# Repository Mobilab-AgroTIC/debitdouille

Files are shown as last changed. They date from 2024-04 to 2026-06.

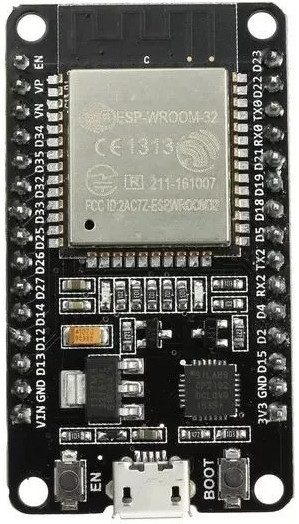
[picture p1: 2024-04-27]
Branchements/esp32.jpg

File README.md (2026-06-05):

# Débitdouille

Débitdouille est un système à construire soi-même permettant de suivre les paramètres de pulvérisation en temps réel.

Ces paramètres sont :
- La pression du circuit,
- les débits des sections,
- la vitesse d'avancement.

Tous ces paramètres sont affichés dans la cabine sur le smartphone (Android) du tractoriste via Bluetooth.
Débitdouille a été développé par la CA34 et le mobilab AgroTIC dans le cadre du projet Occitanum. Il est maintenant largement amélioré par Furgo (furgo.fr)

Le [tutoriel d'installation est disponible sur ce lien ](https://mobilab.agrotic.org/2024/11/28/debitdouille/)

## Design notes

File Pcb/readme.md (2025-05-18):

# Débitdouille – Électronique

> Gestion de la partie électronique du projet Débitdouille.

---

## 📑 Description

La partie électronique de **Débitdouille** est responsable de :
- L'acquisition de mesures physiques (débit, pression).
- La gestion de l'alimentation.
- La communication avec l'application.

---

## 🖧 Architecture Électronique

```text
+-------------------------------+
|           Capteurs            |
| - 2 x Débitmètres SIKA         |
| - 1 x Capteur de pression      |
+--------------+----------------+
               |
      +--------v--------+
      |  Microcontrôleur  |
      |     ESP32         |
      +--------+--------+
               |
      +--------v--------+
      |   Module de comm  |
      |    (Wi-Fi / BLE)  |
      +------------------+
```
## 📋 Historique des Versions

### [v1.1] - A venir
- Protection contre l'inversion de polarité 12V
- Ajout résistane pullup 
- Ajout ports débitmètres supplémentaires
- Routage : cloutage, largeur de piste 

### [v1.0] - 2025-05-12
- Première version en production.
- Schéma validé.
- Déploiement du PCB v1.
- Tests fonctionnels réalisés.

## 👥 Auteur et contributeurs 

Christophe Auvergne CA34

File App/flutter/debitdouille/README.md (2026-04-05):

# debitdouille_v2

A new Flutter project.

## Getting Started

This project is a starting point for a Flutter application.

A few resources to get you started if this is your first Flutter project:

- [Lab: Write your first Flutter app](https://docs.flutter.dev/get-started/codelab)
- [Cookbook: Useful Flutter samples](https://docs.flutter.dev/cookbook)

For help getting started with Flutter development, view the
[online documentation](https://docs.flutter.dev/), which offers tutorials,
samples, guidance on mobile development, and a full API reference.

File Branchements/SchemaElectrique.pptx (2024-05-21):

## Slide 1

12V

GND

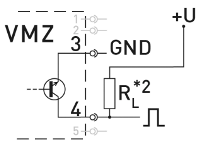
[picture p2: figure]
Push-Pull: VMZ GND 5-1-0— NPN Open Collector: 140— VMZ 31 GND 5 _I_OD PNP Open Collector: VMZ GND *1: Push-Pull switching outputs of several VMZ.2 may not be connected in parallel. *2: Recommendation Pull-Up / Pull-Down resistance RL -2.5 kQ (12 V) or -5 kQ (24 V). Ensure that the maximum si nal c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
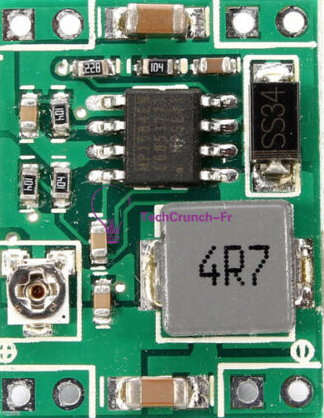
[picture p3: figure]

5V

GND

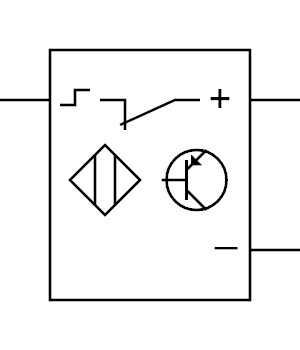
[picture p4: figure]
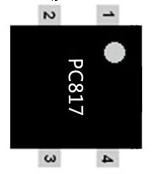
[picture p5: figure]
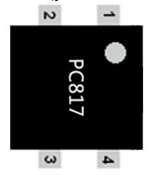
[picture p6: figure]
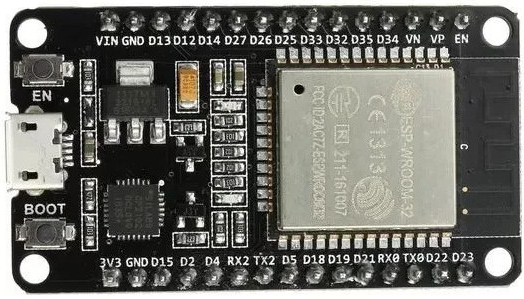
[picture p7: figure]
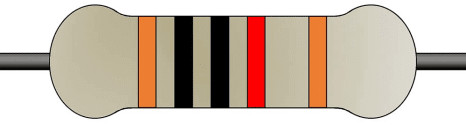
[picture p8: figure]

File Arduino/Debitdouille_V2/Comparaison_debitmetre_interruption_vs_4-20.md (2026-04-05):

# resultats mesure débit avec interruptions 

## Extrait de données brutes PCNT1 vs 4-20_1

## Données PCNT1–4 vs 4-20_1–4

| P (bar) | PCNT1 | PCNT2 | PCNT3 | PCNT4 | 4-20_1 | 4-20_2 | 4-20_3 | 4-20_4 | Vitesse (km/h) |
|:---:|:---:|:---:|:---:|:---:|:---:|:---:|:---:|:---:|:---:|
| -0.30 | 3.96 | 0.00 | 0.00 | 0.00 | 3.99 | 0.00 | 0.00 | 0.00 | 0.4 |
| -0.30 | 4.08 | 0.00 | 0.00 | 0.00 | 3.98 | 0.00 | 0.00 | 0.00 | 0.4 |
| -0.30 | 3.96 | 0.00 | 0.00 | 0.00 | 3.99 | 0.00 | 0.00 | 0.00 | 0.4 |
| -0.30 | 4.02 | 0.00 | 0.00 | 0.00 | 3.98 | 0.00 | 0.00 | 0.00 | 0.4 |
| -0.30 | 4.02 | 0.00 | 0.00 | 0.00 | 3.99 | 0.00 | 0.00 | 0.00 | 0.3 |
| -0.30 | 4.02 | 0.00 | 0.00 | 0.00 | 3.97 | 0.00 | 0.00 | 0.00 | 0.3 |
| -0.30 | 3.96 | 0.00 | 0.00 | 0.00 | 3.96 | 0.00 | 0.00 | 0.00 | 0.2 |
| -0.30 | 4.02 | 0.00 | 0.00 | 0.00 | 3.97 | 0.00 | 0.00 | 0.00 | 0.2 |
| -0.30 | 3.96 | 0.00 | 0.00 | 0.00 | 3.98 | 0.00 | 0.00 | 0.00 | 0.6 |
| -0.30 | 3.96 | 0.00 | 0.00 | 0.00 | 3.92 | 0.00 | 0.00 | 0.00 | 0.6 |
| -0.30 | 3.96 | 0.00 | 0.00 | 0.00 | 3.97 | 0.00 | 0.00 | 0.00 | 0.1 |
| -0.28 | 3.96 | 0.00 | 0.00 | 0.00 | 3.95 | 0.00 | 0.00 | 0.00 | 0.1 |
| -0.28 | 4.02 | 0.00 | 0.00 | 0.00 | 3.97 | 0.00 | 0.00 | 0.00 | 0.6 |
| -0.28 | 3.96 | 0.00 | 0.00 | 0.00 | 3.96 | 0.00 | 0.00 | 0.00 | 0.6 |
| -0.28 | 4.02 | 0.00 | 0.00 | 0.00 | 3.95 | 0.00 | 0.00 | 0.00 | 0.1 |
| -0.28 | 4.02 | 0.00 | 0.00 | 0.00 | 3.97 | 0.00 | 0.00 | 0.00 | 0.1 |
| -0.28 | 3.96 | 0.00 | 0.00 | 0.00 | 3.99 | 0.00 | 0.00 | 0.00 | 0.5 |
| -0.28 | 4.02 | 0.00 | 0.00 | 0.00 | 3.99 | 0.00 | 0.00 | 0.00 | 0.5 |
| -0.28 | 4.02 | 0.00 | 0.00 | 0.00 | 3.94 | 0.00 | 0.00 | 0.00 | 0.2 |
| -0.28 | 3.96 | 0.00 | 0.00 | 0.00 | 3.92 | 0.00 | 0.00 | 0.00 | 0.2 |

## Analyse 
### 📊 Données analysées

- **Nombre de points** : ~70 mesures  
- **Plage de pression (P)** : -0.30 à -0.27 bar  
- **Variables comparées :**
  - **PCNT1 (L/min)** → mesure avec interruptions (non PCNT) avec un ESP32-C3
  - **4-20_1 (L/min)** → signal issu de la conversion 4–20 mA

---

### 📈 Résultats statistiques

| Mesure | Moyenne (L/min) | Écart-type (L/min) | Observations |
|:---|:---:|:---:|:---|
| **PCNT1** | **3.97** | **0.06** | Légère dispersion (valeur brute capteur) |
| **4-20_1** | **3.92** | **0.02** | Signal plus lissé, filtrage probable |
| **Différence (PCNT1 − 4-20_1)** | **+0.05** | **≈ 0.05** | Décalage moyen de +0.05 L/min |

- **Corrélation linéaire (r)** ≈ **0.95 – 0.98** → excellente cohérence entre les deux signaux.  
- **Biais systématique** : le signal 4–20 mA **sous-estime d’environ 1,3 %** le débit Interrupt.

---

L’analyse des écarts observés entre **PCNT1** et **4-20_1** montrait une dispersion anormale pour PCNT de ±0.06 L/min.  
Après vérification, cette erreur ne provient **pas d’un décalage de calibration**, mais du **temps d'intégration des pulses (1000 ms)** utilisé pour mesurer la fréquence du débitmètre.

---

### ⚙️ Analyse du problème

- Fréquence moyenne du capteur : **≈ 65 Hz** (soit ~65 impulsions/s)
- À **200 ms**, cela correspond à environ **13 impulsions** par période.

| Pulses comptés | Débit calculé (L/min) |
|:---:|:---:|
| 12 | 3.6 |
| 13 | 3.9 |
| 14 | 4.2 |

➡️ Une variation de ±1 pulse entraîne une **erreur de ±0.3 L/min**, soit près de **8 % d’écart** !

- À **1000 ms**, cela correspond à environ **65 impulsions** par période.

| Pulses comptés | Débit calculé (L/min) |
|:---:|:---:|
| 64 | 3.92 |
| 65 | 3.96 |
| 66 | 4.02 |

➡️ Une variation de ±1 pulse entraîne une **erreur de ±0.06 L/min**, soit près de **1.3 % d’écart**

---

### ✅ Solution appliquée

Allonger la période de mesure permet de diminuer l'écart lié au comptage ou non d'un pulse :

### ⚙️ Proposition de correction (calibration de l'un ou l'autre)

Deux approches possibles selon le type de régulation souhaité :

#### 1. Correction par offset constant du capteur 4-20
\[
Q_{\text{corrigé}} = Q_{4-20_1} + 0.05
\]

#### 2. Correction par facteur de gain du capteur 4-20
\[
Q_{\text{corrigé}} = Q_{4-20_1} \times 1.013
\]

> ✅ Ces formules ramènent la moyenne du capteur 4–20 mA au même niveau que celle du capteur PCNT1.

---

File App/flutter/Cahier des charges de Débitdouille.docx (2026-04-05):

Cahier des charges de Débitdouille

Debitdouille est un système open source permettant de suivre en temps réel les paramètres de pulvérisation pour un agriculteur, dans son tracteur, sur son téléphone.

Boitier “hardware”

Un boitier est installé sur le pulvé, il est composé :

- d’un ESP32, qui envoie les données en Bluetooth.

- De paires de débitmètres, un gauche et un droit. Il y a par défaut 1 paire, mais on peut aller jusqu’à 4 paires.

- D’un capteur de pression

- d’un GNSS permettant de calculer la vitesse.

Ce boîtier est branché depuis la cabine du tracteur, en 12V, sur une prise 3 plots. Il possède un régulateur 5V pour faire fonctionner les capteurs.

Les débitmètres et le capteur de pression sont à étalonner, au moins à l’installation du système, et au mieux une fois par an.

Les données du boitier installé sur le puvlé sont affichées sur le smartphone de l’agriculteur via connexion bluetooth. Il y a donc 3 types d’infos principales à afficher ;

· Pression de la cuve, grâce à un capteur de pression

· Débit. Il peut y avoir plusieurs débitmètres installés sur le pulvé. Ils viennent par paire : Débit gauche 1 et débit droit 1, Débit gauche 2 et débit droit 2, Débit gauche 3 et débit droit 3.

· La vitesse est également donnée avec un GPS car celle donnée par le tracteur n’est pas bonne.

L’application peut choisir de se connecter à un objet en bluetooth BLE pour recevoir les trames DATA toutes les secondes en format JSON dans le format suivant :

{"P":"1.24","V":"7.30","DG1":"2.34","DD1":"0.29","DG2":"0.87","DD2":"0.00","DG3":"2.04","DD3":"1.11"","DG4":"2.04","DD4":"1.11"}

Application “software”

L’application doit être simple, intuitive, sans fioritures.

## Technologie :

L’application est développée en Flutter. Elle est composée de plusieurs fichiers qui correspondent à une architecture classique d’un projet flutter (main, screens, widgets, etc)

## Pages :

Je décris ici les pages. Le style est simple : tout est en fond noir, écrit en blanc, le plus gros possible.

- Base :

Ceci est commun à toutes les pages. C’est TOUJOURS affiché, sur les pages décrites ci-dessous !
Il y a un en-tête avec un bouton « paramètres ». Ceci ouvre un onglet sur le côté, et on peut alors choisir entre les pages :

La page Accueil, la page de connexion, la page d’Etalonnage des capteurs, et la page de paramètres.

Sur l’en-tête, on trouve également un petit rond vert. Ce rond vire au rouge si aucune donnée n’a été reçue depuis 3secondes. Cela permet de s’assurer que le système est toujours connecté.

il y a un bouton en bas à droite permettant de simuler l’arrivée d’une trame json. Ce bouton peut être masqué, cela dépendra des options choisies dans la page des paramètres de l’appli.

A gauche de ce bouton, tout en bas, on peut lire la dernière trame arrivée. Cela permet de débugguer. Cette trame json provient du bouton simulation OU du module Bluetooth.

L’exemple est donné ci-dessous :

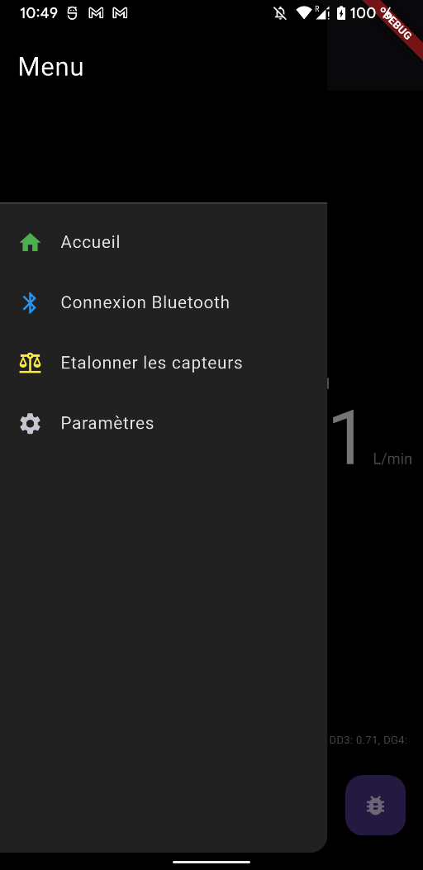
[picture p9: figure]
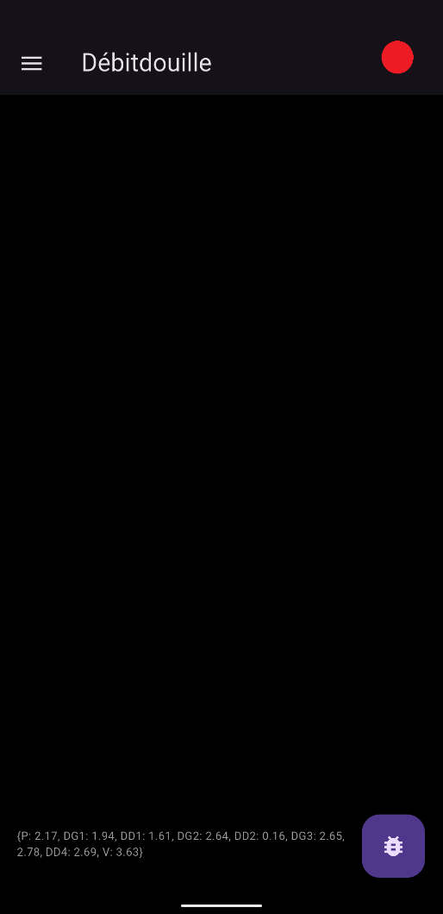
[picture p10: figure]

A gauche, le scaffold avec les objets principaux. A droite, le menu avec les 4 pages.

- page Accueil

La page d’accueil de débitdouille est noir, avec écrit en blanc et en gros plusieurs chiffres :

- En haut, centré, la pression.

- Au milieu, les débits :

- le (ou les) débits gauches à gauche

- le (ou les) débits droits à droite

- En bas, centré, la vitesse.

Comme c’est la page d’accueil, au début, toutes les valeurs sont à zéro.

Il est possible d’avoir plusieurs paires de débits gauche ou droit. Cela dépendra des options choisies dans la page des paramètres de l’appli.

Quoi qu’il arrive, l’affichage des débits est toujours au milieu de l’app, sur la gauche pour le debits gauche, et sur la droite pour les débit droits. Cela peut aller jusqu’à 4 débits gauche et 4 débits droit. La trame json contiendra toujours 4 paires de débits

Ces chiffres sont en gros. Au dessus de chaque chiffre, il est écrit en plus petit ce que c’est (pression, DG1, DG2, DD1, DD2, vitesse, ). Il y a 2 décimales pour ces valeurs. Il y a aussi l’unité (bars, L/min ou km/h) affiché en petit, à droite du chiffre.

Un exemple de cette page :

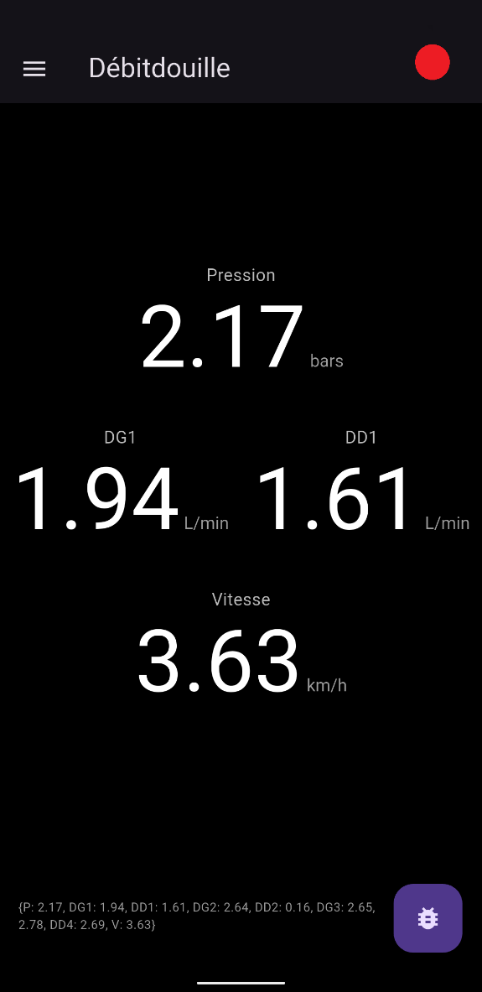
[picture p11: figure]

Ci-dessus, la page d’accueil.

- page Connexion

La page de connexion permet d’appairer le boîtier. On peut lancer un scan et voir les appareils BT à proximité. Dès qu’une connexion est faite avec un module, on revient automatiquement sur la page principale, et on voit que les données sont mises à jour via le module Bluetooth. Si ça bugue, par exemple mauvais UUID, ça met un message d’erreur « connexion échouée »

- page Paramètres

La page des paramètres présente des boutons, qui permet de modifier l’interface :

- On peut choisir le nombre de paires de débits avec 1, 2, 3 ou 4 paires. Cela forcera à l’écran le nombre de paires de débits à afficher.
- Un bouton à cocher ‘debug’ permet de masquer ou afficher la trame json, affichée dans la page principale, faisant office de débug.
- Un bouton à cocher ‘simulation’ permet d’afficher sur la page principale un petit bouton, qui envoie une trame json fictive a chaque appui du bouton. Le bouton est masqué par défaut.

Si on rallume l’application, elle garde en mémoire les infos (il ne faut pas remodifier les réglages a chaque fois). Il n’y a pas de boutons « enregistrer » dans cette page, ça se fait automatiquement.

- page Calibration

Chaque capteur est calibré avec un coefficient A et B, de la façon ValeurCalibrée = A * ValeurBrute + B. Les trames JSON n’envoie que les valeurs calibrées.

La page de calibration permet de visualiser les coefficients du capteur, stocké sur l’ESP32, et de les corriger.

Chaque capteur est accessible avec une liste d’onglets en haut de l’écran, comme un carroussel de tous les capteurs (Pression, DG1, DG2, …)

Dans la suite, je parle de l’onglet P (pression) mais les autres sont similaires.

On a un bouton « récupérer les coefficients », qui permet d’afficher dans les CASES a ET b les coefficients stockées dans l’ESP32. La trame envoyée est de ce style, il suffira juste de filtrer pour le capteur voulu

{

"coeff": {

"DG1": {"A": 1.0, "B": 0.0},

"DD1": {"A": 1.0, "B": 0.0},

"P": {"A": 1.0, "B": 0.0}

}

On affiche alors : La Valeur brute (l’inverse de la formule mathématique ci-dessus), et la valeur calibrée.

On peut modifier manuellement les cases A et B pour changer de coefficient, cela modifiera la valeur calibrée affichée directement. Si on appuie sur « envoyer les coefficients », on va envoyer une trame json à l’esp32, qui va écraser les anciens coefficients et les mettre à jour. Cette trame json est du style :

{

"update_coeff": {

"DG1": {"A": 1.2, "B": -0.1},

}

}

Un exemple de page :

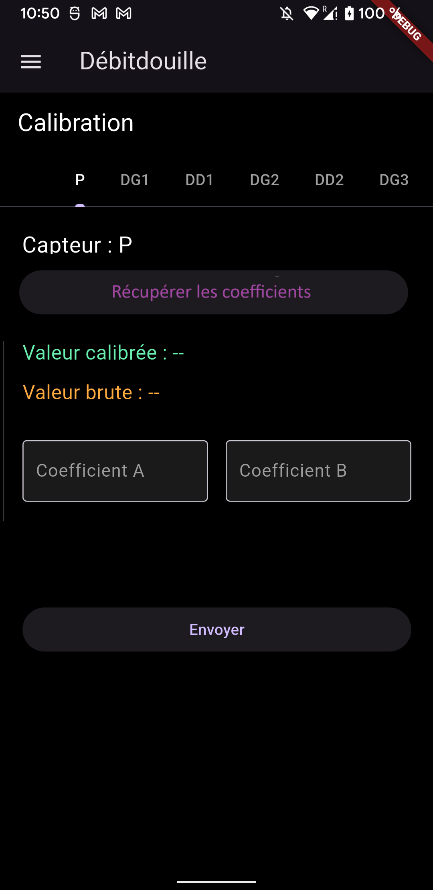
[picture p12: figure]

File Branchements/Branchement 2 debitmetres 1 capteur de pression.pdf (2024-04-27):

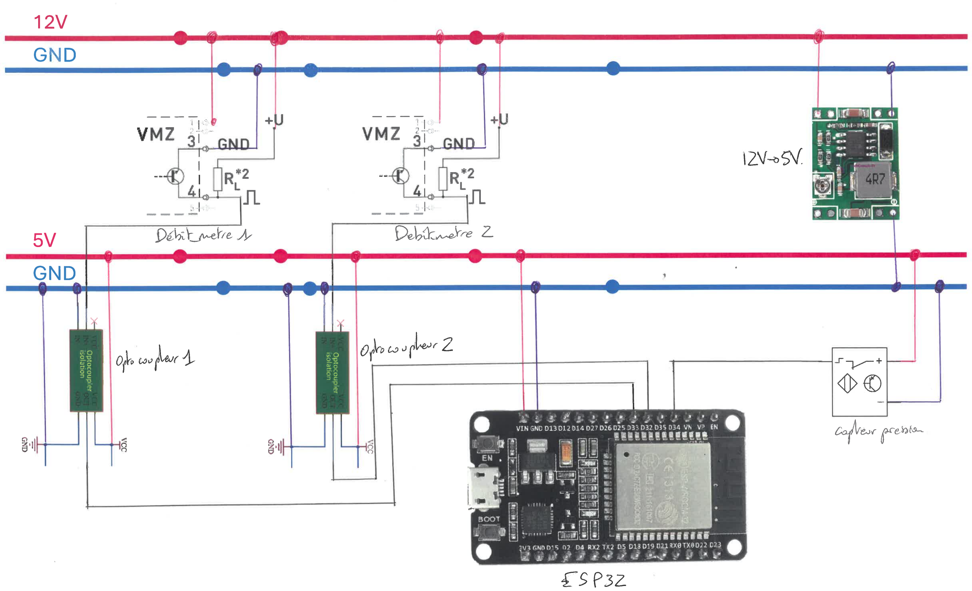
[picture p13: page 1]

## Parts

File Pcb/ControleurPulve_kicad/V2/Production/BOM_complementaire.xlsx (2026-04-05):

Qté | Part | MF | MPN | Comment | Lien 1 | Lien 2
1 | PCB carte mère | JLC PCB
1 | regulateur DC DC |  | TRS2-2450 | 5V 2A
1 | XIAO ESP32-C3
1 | antenne Bluetooth ipex
1 | GPS neo 7M |  | GY-NEO6MV2
1 | connecteur ipex SMA
8 | cavalier
1 | DC jack receptacle |  |  | optionnel si utilisé
1 | connecteur extension | JST | ? | optionnel si utilisé
1 | connecteur I2C |  | ? | optionnel si utilisé

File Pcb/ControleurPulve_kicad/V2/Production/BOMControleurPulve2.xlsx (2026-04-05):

Designator | Comment | Datasheet | Footprint | Qty | DNP | JLCPCB Part | MPN
C1,C4,C5,C7,C10,C11,C13,C15,C17,C18 | 100nF | ~ | Capacitor_SMD:C_0603_1608Metric,Capacitor_SMD:C_0603_1608Metric_Pad1.08x0.95mm_HandSolder,Capacitor_SMD:C_0805_2012Metric | 10 |  | C1591 | CL10B104KB8NNNC
C2 | 470uF 50V | ~ | Capacitor_SMD:CP_Elec_8x10 | 1 |  | C4054388 | VP1H221M0810
C3,C6,C14,C16 | 10uF X5R | ~ | Capacitor_SMD:C_0603_1608Metric_Pad1.08x0.95mm_HandSolder,Capacitor_SMD:C_0805_2012Metric | 4 |  | C2932476 | CL21A106KBYQNNE
C8 | 10nF | ~ | Capacitor_SMD:C_0603_1608Metric | 1 |  | C5137477 | FCC0603B103K500CT
C9,C12 | 1uF | ~ | Capacitor_SMD:C_0603_1608Metric | 2 |  | C14663 | CC0603KRX7R9BB104
D1 | MRA4004T3G | http://www.onsemi.com/pub_link/Collateral/MRA4003T3-D.PDF | Diode_SMD:D_SMA | 1 |  | C40324 | MRA4004T3G
D2 | LESD5D5.0CT1G | https://www.onsemi.com/pdf/datasheet/esd5z2.5t1-d.pdf | Diode_SMD:D_SOD-523 | 1 |  | C5199159 | LESD5D5.0CT1G
D3 | green | ~ | LED_SMD:LED_0603_1608Metric_Pad1.05x0.95mm_HandSolder | 1 |  | C19273151 | YLED0603G
D4 | blue | ~ | LED_SMD:LED_0603_1608Metric_Pad1.05x0.95mm_HandSolder | 1 |  | C19171394 | YLED0603B
D5 | red | ~ | LED_SMD:LED_0603_1608Metric_Pad1.05x0.95mm_HandSolder | 1 |  | C19171390 | YLED0603R
F1 | RUILON SMD1812P050TF/30 | ~ | Diode_SMD:D_1812_4532Metric_Pad1.30x3.40mm_HandSolder | 1 |  | C12559 | SMD1812P050TF/30
J1 | Screw_Terminal_01x02 | ~ | TerminalBlock_Phoenix:TerminalBlock_Phoenix_MKDS-1,5-2-5.08_1x02_P5.08mm_Horizontal | 1 |  | C8465
J5 | Screw_Terminal_01x02 | ~ | TerminalBlock_4Ucon:TerminalBlock_4Ucon_1x02_P3.50mm_Horizontal | 1 |  | C784940
J8,J9,J12,J13,J14,J15,J18,J19 | Conn_01x03_Pin | ~ | Connector_PinHeader_2.54mm:PinHeader_1x03_P2.54mm_Vertical | 8 |  | C6332196 | HB-PH3-25413PB2GOP
J10,J11,J16,J17 | Screw_Terminal_01x04 | ~ | TerminalBlock_Phoenix:TerminalBlock_Phoenix_MKDS-3-4-5.08_1x04_P5.08mm_Horizontal | 4 |  | C42377749 | WJ500V-5.08-4p
R1,R2,R3,R13,R14,R24 | 2.2k | ~ | Resistor_SMD:R_0603_1608Metric_Pad0.98x0.95mm_HandSolder | 6 |  | C114662 | RC0603FR-072K2L
R4 | 150R .1% | ~ | Resistor_SMD:R_0805_2012Metric | 1 |  | C351609 | PTFR0805B150RN9
R5,R6,R15,R16 | 10k | ~ | Resistor_SMD:R_0603_1608Metric | 4 |  | C98220 | RC0603FR-0710kL
R7,R8,R17,R18 | 1k | ~ | Resistor_SMD:R_0603_1608Metric | 4 |  | C22548 | RC0603FR-071kL
R9,R10,R11,R12,R19,R20,R21,R22,R23 | 2k5 | ~ | Resistor_SMD:R_0603_1608Metric | 9 |  | C304065 | AR03BTC2501
U1 | TSR2-2450 | https://www.recom-power.com/pdf/Innoline/R-78Exx-0.5.pdf | Converter_DCDC:Converter_DCDC_TRACO_TSR2-xxxx_THT | 1 |  | C5198099 | TSR2-2450
U3 | BTS7004-1EPP | https://www.infineon.com/dgdl/Infineon-BTS7004-1EPP-DS-v01_00-EN.pdf?fileId=5546d4626102d35a016147550a725555 | Package_SO:Infineon_PG-TSDSO-14-22 | 1 |  | C534825 | BTS7004-1EPP
U4 | ADS1115IDGS | http://www.ti.com/lit/ds/symlink/ads1113.pdf | Package_SO:TSSOP-10_3x3mm_P0.5mm | 1 |  | C37593 | ADS1115IDGSR
U5,U6,U7,U8 | PC817 | http://www.soselectronic.cz/a_info/resource/d/pc817.pdf | Package_DIP:DIP-4_W8.89mm_SMDSocket_LongPads | 4 |  | C20612591 | PC817CS

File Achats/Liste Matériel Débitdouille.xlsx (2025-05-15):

Nom | Commentaire | Lien d'achat | Prix TTC | Quantité | Prix total
Carte électronique
Carte électronique "PCB" | Carte éléctronique | Cf tutoriel |  | 1
Carte NodeMCU ESP32 | micro-processeur (le cerveau) | https://www.gotronic.fr/art-module-nodemcu-esp32-28407.htm | 13.9 | 1 | 13.9
Câble micro-USB DATA | connectique | https://www.gotronic.fr/art-cordon-50-cm-rs105-33657.htm | 1.95 | 1 | 1.95
Boîte de dérivation étanche IP65 (ou IP54) 121x121x68 | boitier de protection | https://pro.manomano.fr/p/boite-de-derivation-etanche-ip65-ou-ip54-avec-passes-fils-coniques-31932558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 | 1.9 | 1 | 1.9
Capteur pression
Capteur de pression | Capteur de pression | https://www.gotronic.fr/art-capteur-de-pression-sen0257-27841.htm | 24.8 | 1 | 24.8
Mamelon mâle-mâle 1/4"-1/4" AMA | Raccord | https://pro.manomano.fr/p/mamelon-male-male-1-4-1-4-ama-5962804?product_id=6160036 | 0.75 | 1 | 0.75
Té inox égal Femelle 1/4 | Raccord | https://pro.manomano.fr/p/te-inox-egal-femelle-1-4-7572691?product_id=7852283 | 2.21 | 1 | 2.21
Coude 90° Male / femelle en inox 316 1/4'' | Raccord | https://pro.manomano.fr/p/coude-90-male-femelle-en-inox-316-1-4-pouce-5701506?product_id=5876294 | 1.98 | 1 | 1.98
Rouleau TEFLON | Rteflon | https://pro.manomano.fr/p/ruban-teflon-ptfe-geb-epaisseur-superieure-506781 | 1.12 | 1 | 1.12
Débitmètre
Débitmètre | Capteur débitmètre | Cf tutoriel |  | 2
Cable Débitmetre | câble | Cf tutoriel |  | 2
Connexion rapide filetage mâle 3/8'' Quick Connect | Raccord | https://pro.manomano.fr/p/kit-adaptateur-a-connexion-rapide-pour-nettoyeur-haute-pression-filetage-male-95-mm-5000-psi-38-quick-connect-kit-male-73726998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 | 10.79 | 4 | 43.16
Manchon laiton réduit Femelle 1/2-3/8 | Raccord | https://pro.manomano.fr/p/manchon-laiton-reduit-504991 | 1.59 | 4 | 6.36
Embout laiton cannelé Ø16 Femelle 1/2 | Raccord (A adapter en fonction du tuyau du pulvé !) | https://pro.manomano.fr/p/raccord-laiton-embout-male-cannela-femelle-fileta-23756363 | 2.55 | 4 | 10.2
Collier de Serrage Tuyau | Quicaillerie | https://pro.manomano.fr/p/fei-yu-12-pieces-collier-de-serrage-tuyau-ajustable-en-acier-inoxydable-tuyau-pinces-clips-fixation-16-25-mm-51084963 | 12.32 | 1 | 12.32
GPS
GPS | Capteur GPS | https://www.gotronic.fr/art-module-gps-u-block-neo-7m-wpi430-28516.htm | 29.9 | 1 | 29.9
Antenne GPS | Capteur GPS | https://www.gotronic.fr/art-antenne-gps-sma-sma960-20941.htm | 19.9 | 1 | 19.9
Alimentation
Cable Alimentation | câble | https://pro.manomano.fr/p/cable-dalimentation-electrique-ho3vvh2-f-2x-075-10m-blanc-noir-marron-ou-or-3549774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 | 4.42 | 1 | 4.42
Prise 3 plot male | connectique | https://pro.manomano.fr/p/socle-3-plots-femelle-4-points-de-fixation-vrac-sodise-16444-29353700?product_id=6161037 | 3.42 | 1 | 3.42
Prise 3 plot femelle pour doublettte | connectique | https://pro.manomano.fr/p/socle-3-plots-femelle-4-points-de-fixation-vrac-sodise-16444-29353700 | 3.42 | 1 | 3.42
Total |  |  |  |  | 181.71

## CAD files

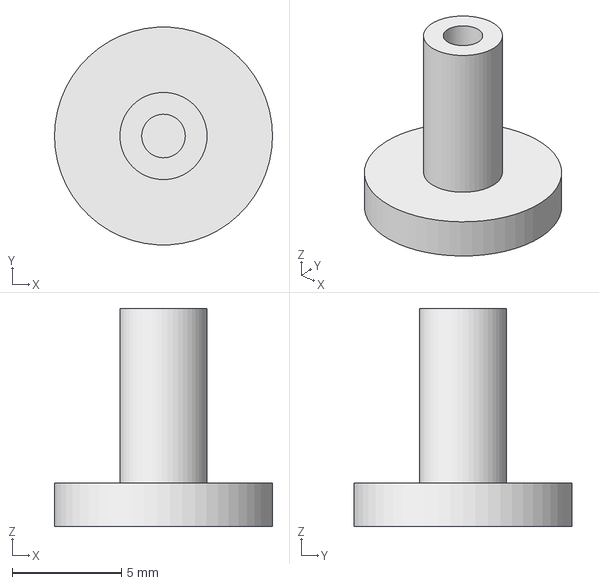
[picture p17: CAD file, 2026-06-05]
Impression3D/Support PCB.FCStd
10.0 x 9.98 x 10.0 mm

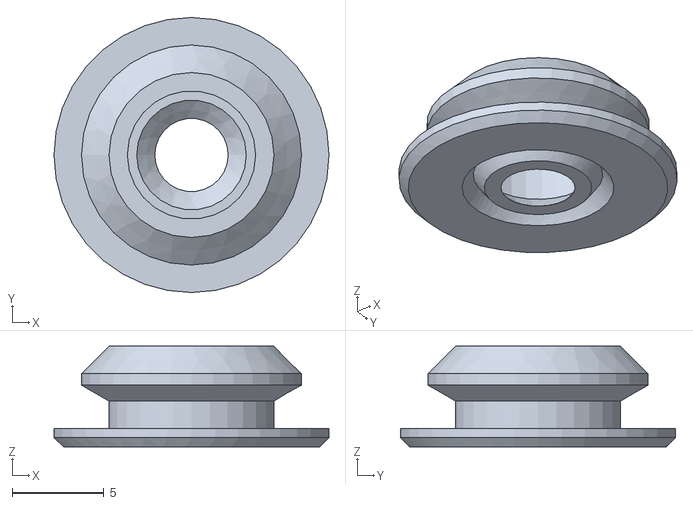
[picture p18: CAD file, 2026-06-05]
Impression3D/PasseFil-BodyChamfer001.stl
15.0 x 15.0 x 5.50

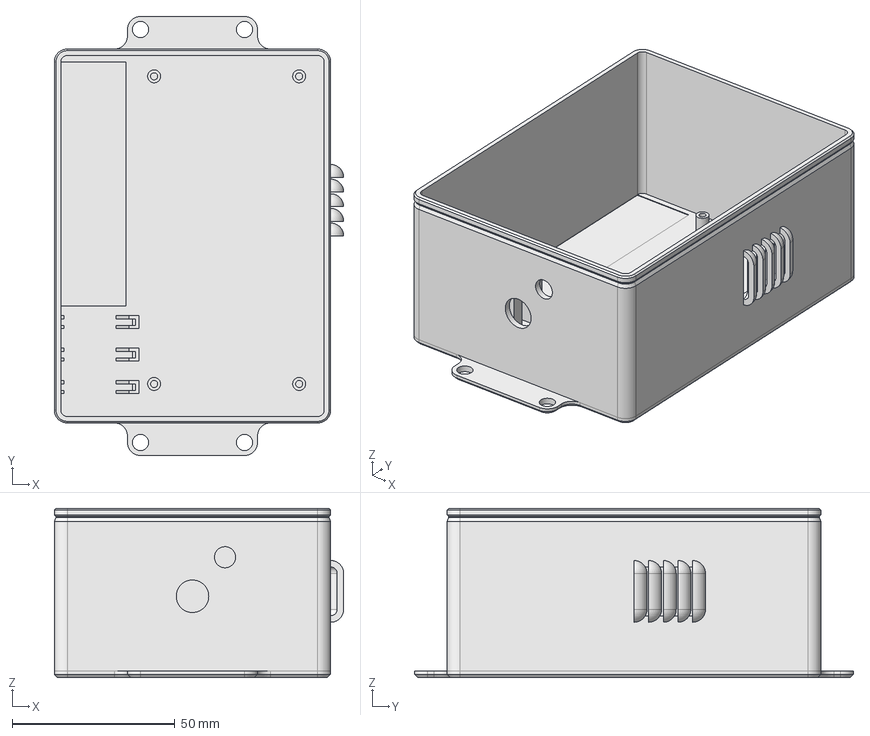
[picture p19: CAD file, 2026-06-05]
Impression3D/Boite PCB.FCStd
89.0 x 135.0 x 52.0 mm

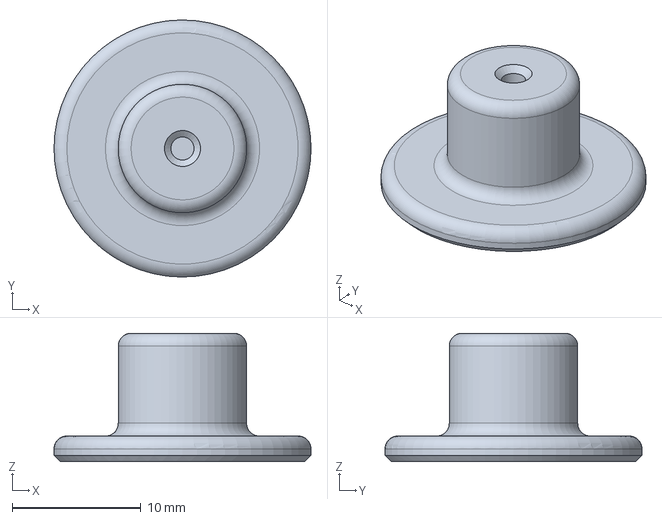
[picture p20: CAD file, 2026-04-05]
Impression3D/supportCarte.FCStd
20.0 x 20.0 x 10.0 mm

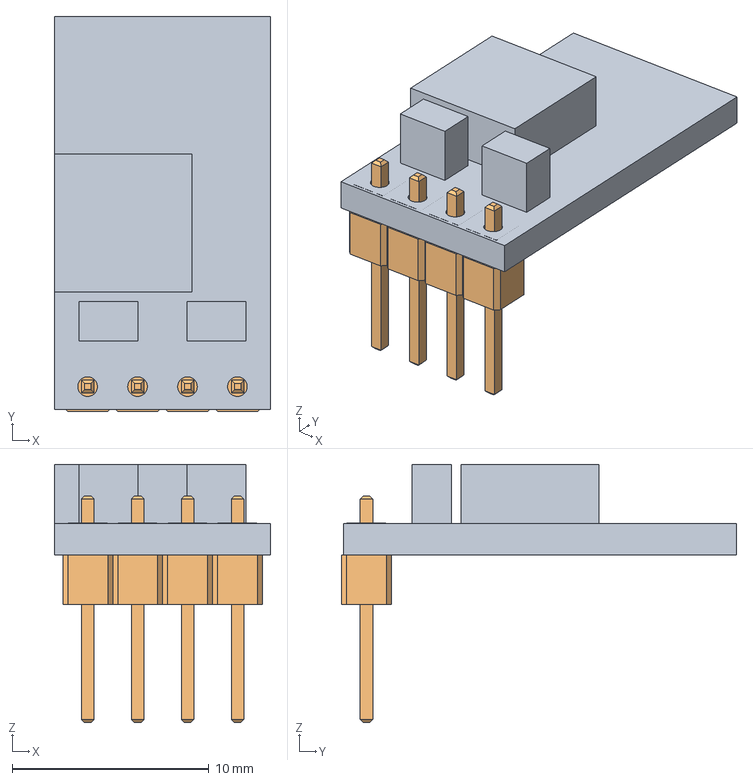
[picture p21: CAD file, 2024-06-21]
Impression3D/Convertisseur de tension.FCStd
11.0 x 20.1 x 13.1 mm
PinHeader_1x04_P2

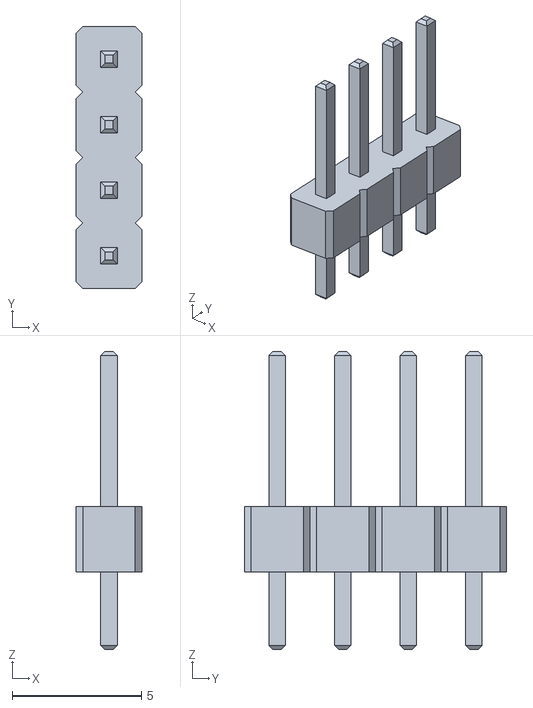
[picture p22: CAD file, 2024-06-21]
Impression3D/PinHeader_1x04_P2.stl
2.54 x 10.2 x 11.5

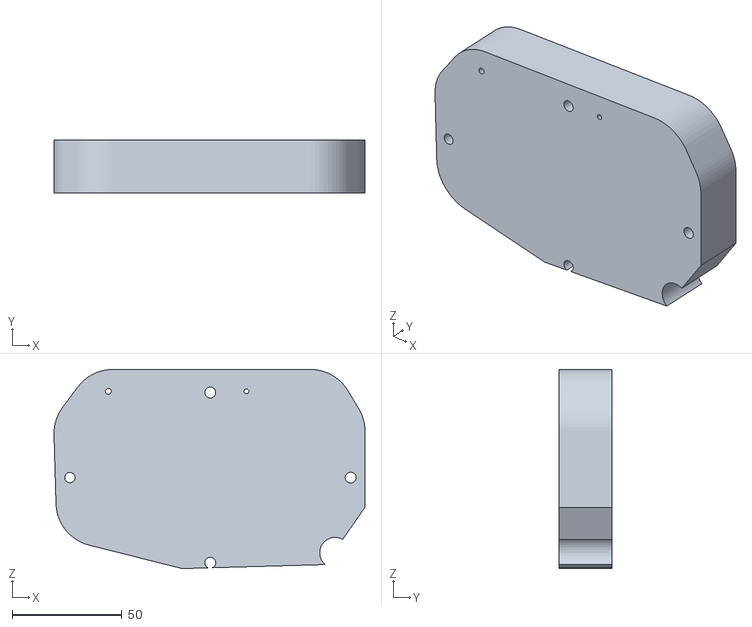
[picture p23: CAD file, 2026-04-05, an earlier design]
Pcb/ControleurPulve_kicad/V1/ExportPlaqueDebitdouilleSTL.stl
142.0 x 24.0 x 90.9

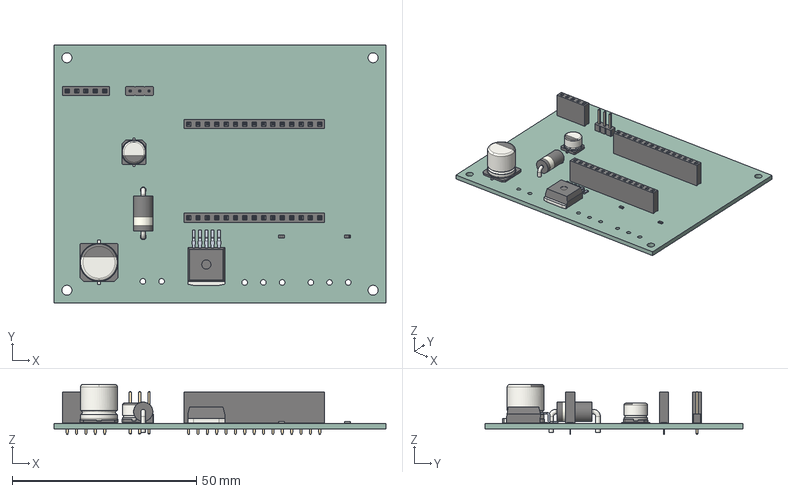
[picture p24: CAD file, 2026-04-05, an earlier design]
Pcb/ControleurPulve_kicad/V1/ControleurPulve.step
90.0 x 70.0 x 13.6 mm
CQ assembly
R_0603_1608Metric x 2
PinSocket_1x15_P2.54mm_Vertical x 2
PinHeader_1x03_P254mm_Vertical
PinSocket_1x05_P2.54mm_Vertical
CP_Elec_63x54
CP_Elec_10x105
D_DO-201AD_P12.70mm_Horizontal
ControleurPulve_PCB

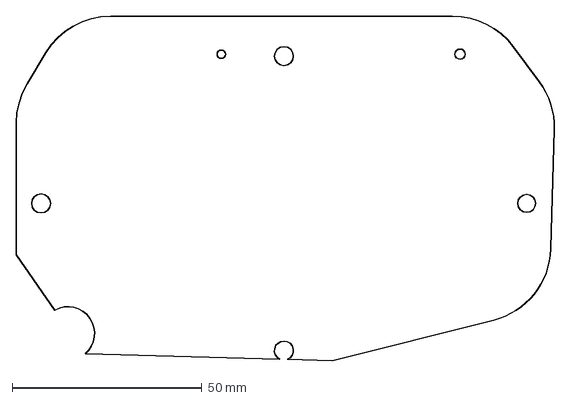
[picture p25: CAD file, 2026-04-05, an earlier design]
Pcb/ControleurPulve_kicad/V1/PlaqueBoitierDebitdouille.dxf
142.1 x 90.9 mm

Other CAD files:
Impression3D/PasseFil.FCStd
Impression3D/PinHeader_1x04_P2.54mm_Vertical.FCStd
Impression3D/Boite PCB.stl
Impression3D/Support PCB.stl
Impression3D/supportCarte.stl

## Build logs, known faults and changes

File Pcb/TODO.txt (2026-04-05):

V1

- cloutage 
- piste power 
- Protection inversion de polarité 
- Capteur de pression 0-5V => pin ESP 3.3V !!!
- ESP32 a des moindres capacités analogiques 
- régulateur moins cher 
- Besoin Opto SIKA ? version à 4 fils
- Chanegr empreinte self (introuvable si petit pour 3A !)
- multi empreinte ESP
- Multi empreinte GPS 

V2 
- intergation CMS ESP 
- intégration CMS GPS ? 
- Sortie pression Analogique --> sensibilité au bruit EMC ! prendre un capteur 4-20 mA

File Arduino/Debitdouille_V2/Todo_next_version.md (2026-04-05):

# À prévoir pour la prochaine version V2.1
## Erreur / améliorations constatées V2.0
- Silkscreen manquant prod ??? 
- changer la valeur de la résistance des capteurs 4-20 : utiliser toute la gamme de l'ADS1115 gain 1 = 2048mV => résistance de 100R pour lire 2V à 20mA
- détecter les alimentations pour ne pas allumer l'output quand il n'y a pas de 12V in 
- flyback diode connecteur debitmètre 
- pourquoi on retrouve du 5V sur le 12V quand on alimente par USB ? 
- pins Rx et Tx GPS pour le modèle 2 inversés

## é verifier 
- Remplacement de l’ESP par une version plus intégrée et avec plus de pins
- L’ESP doit pouvoir lire et reporter l’ensemble des tensions de la carte à des fins de dépannage
- Choix de l’architecture capteur de pression
- Choix de l’architecture débitmètre
- Gain de place : dimuntion à 2 debitmètres, les autres sur extension ?
- connecteurs débitmètres ?

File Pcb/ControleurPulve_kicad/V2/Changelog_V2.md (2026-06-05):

# Changelog V2.0

Cette carte est une proposition d'amélioration de la base existante sans toutefois être une refonte complète.  
Elle permet de tester des fonctionnalités pour les débitmètres et capteurs de pression.  Elle intègre aussi des protections simples (polarité court-circuit) pour protéger l'électronique. 
Rétrocompatible avec l'ancien système, à l'exception du pin mapping du microcontrôleur.

---

## Power

- Entrée via jack DC (avantage : pas d'inversion possible) ou bornier à vis
- Ajout d'une diode de protection contre la polarité inversée
- Fusible réarmable 500 mA continu
- Régulateur DCDC à découpage 5V 2A
- Contrôle de l'alimentation 12V (sortie on/off) avec BTS7004

---

## Microcontrôleur (µC)

- ESP32-C6 SuperMini avec connecteur IPEX
- Attention : aucun pin de disponible en réserve

---

## Capteur de pression

- Alimentation 5V, sortie analogique 3.3V (les pins de l’ESP ne sont pas tolérants au 5V)
- Possibilité d’ajout de capteur 4-20 mA (moins de bruit)
- Pads de sélection pour choisir l’un ou l’autre

---

## Débitmètre

- Possibilité d’en connecter 4
- Bornier 4 fils compatible SIKA
- Le fil non utilisé est une sortie 4-20 mA → Voir multiplexer ADC  
  → Proposition : interroger tous les débitmètres en 4-20 mA via un multiplexeur analogique ? À tester
- Jumper de sélection alimentation : 5V / 12V
- Jumper de sélection : PNP / NPN / push-pull avec résistance de 2.5 kΩ
- Ajout de résistance pour limiter le courant dans la LED de l’opto
- Pull-up de la sortie opto en 3.3V (les pins de l’ESP ne sont pas tolérants au 5V)

---

## Multiplexeur ADC

- À tester
- Prend en charge 4 voies
- Pad de sélection de l’alimentation (3.3V en routine)
- Pad de sélection d’adresse I2C → voir connecteur d’extension
- Lecture des 4 débitmètres ou des capteurs de pression en 4-20 mA

---

## Connecteur d’extension I2C

- Connecteur Grove simple pour ajouter un capteur
- Connecteur d’extension pour débitmètres :
  - Cette carte sera un esclave I2C
  - Alimentera les 4 débitmètres
  - Intégrera un composant de lecture (Mux ADC si 4-20 mA choisi)  
    → Utilité de pouvoir sélectionner l’adresse I2C du Mux, autre solution en I2C ?

---

## GPS

- Sélection de l’alimentation

---

## Général

- Pads de test
- LED d’alimentation (debug facile et peu coûteux)
- Trous de fixation
- Boîtier

---

## Non implémenté

- Pas de possibilité de tester un débitmètre à ultrasons (manque de pins)
- Pas de double empreinte ESP
- Pas de double empreinte GPS ou intégration directe

---

## À prévoir pour la prochaine version V2.1
BUG
- Ajouter Zener Diode protection entrée 4-20 : 3.3V 
- Changer R shunt 4-20 debitmètres (pas pression) : 100R
- Changer référence diode protection input : chute tension trop élevée (viser 150mV), ou passer sur protection mosfet 

Choix
- Remplacement de l’ESP par une version plus intégrée et avec plus de pins
- L’ESP doit pouvoir lire et reporter l’ensemble des tensions de la carte à des fins de dépannage
- Choix de l’architecture capteur de pression
- Choix de l’architecture débitmètre
- Gain de place : dimuntion à 2 debitmètres, les autres sur extension ?
- connecteurs débitmètres ? 
- full isolation 12V périphériques (+cher)

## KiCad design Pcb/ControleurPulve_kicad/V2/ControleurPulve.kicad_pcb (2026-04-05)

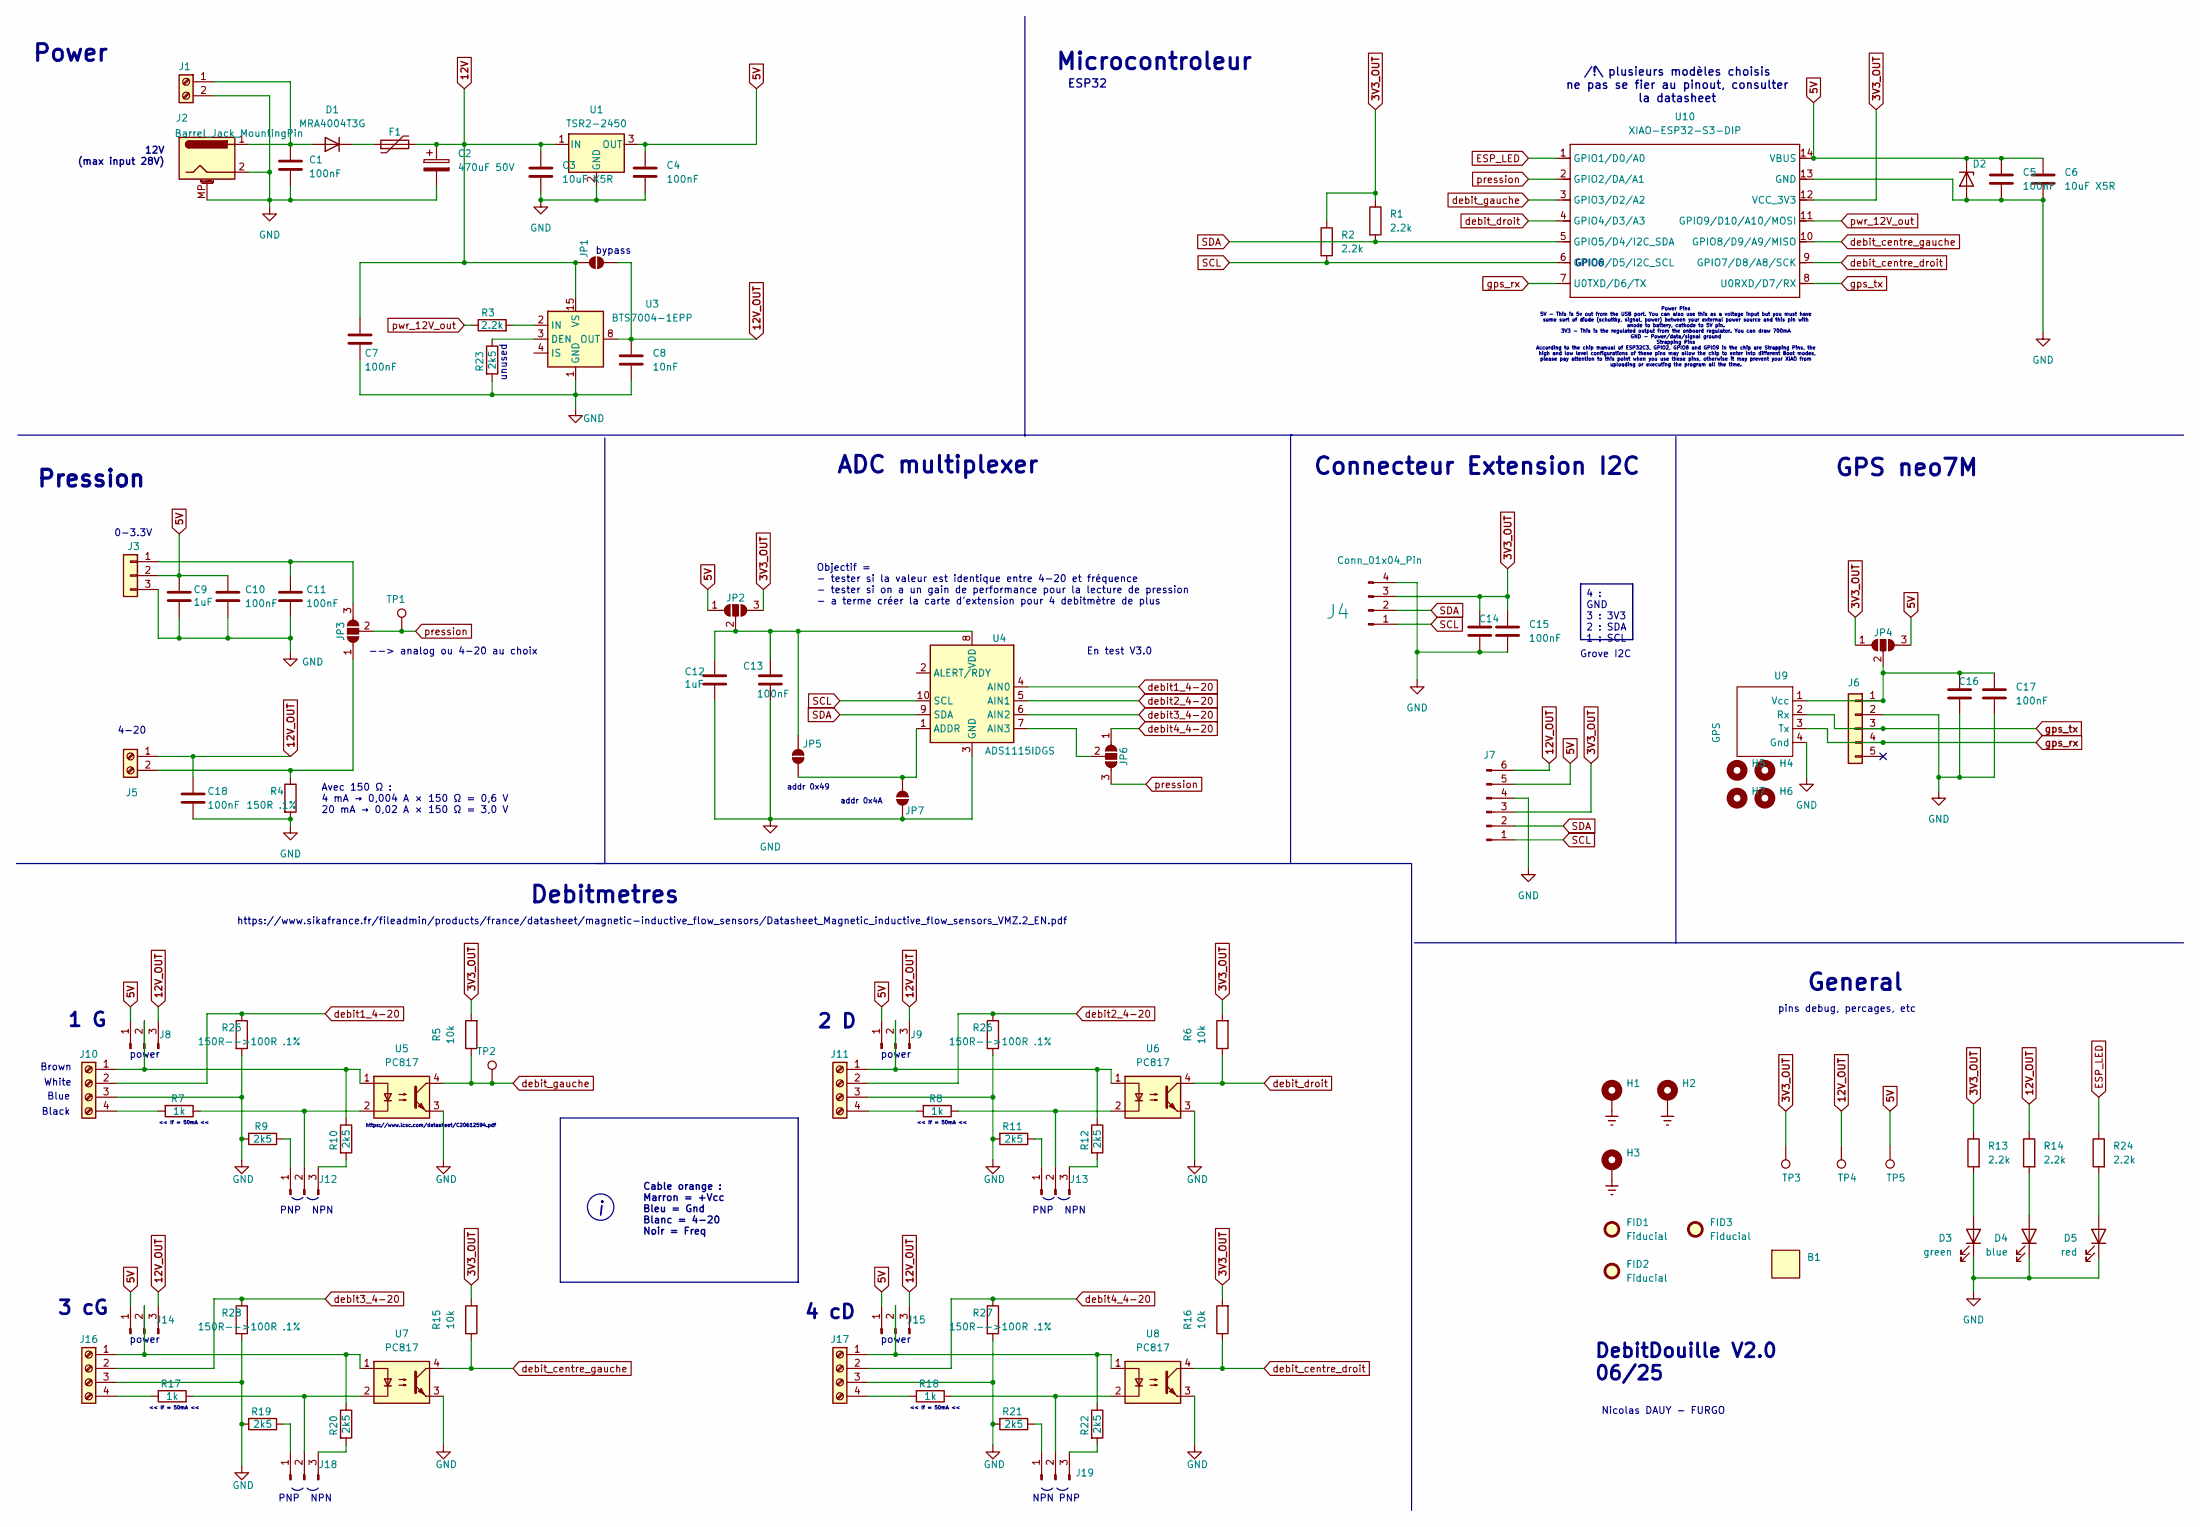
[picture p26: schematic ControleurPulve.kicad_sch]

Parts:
B1: EL161_box_enclosure_IDE
C1, C4, C5, C7: 100nF; C_0805_2012Metric; MPN CL10B104KB8NNNC; LCSC C1591
C2: 470uF 50V; CP_Elec_8x10; MPN VP1H221M0810; LCSC C4054388
C3, C6: 10uF X5R; C_0805_2012Metric; MPN CL21A106KBYQNNE; LCSC C2932476
C8: 10nF; C_0603_1608Metric; MPN FCC0603B103K500CT; LCSC C5137477
C9, C12: 1uF; C_0603_1608Metric; MPN CC0603KRX7R9BB104; LCSC C14663
C10, C11, C18: 100nF; C_0603_1608Metric; MPN CL10B104KB8NNNC; LCSC C1591
C13: 100nF; C_0603_1608Metric; MPN CL10B104KB8NNNC; JLCPCB Part C14663
C14, C16: 10uF X5R; C_0603_1608Metric_Pad1.08x0.95mm_HandSolder; MPN CL21A106KBYQNNE; LCSC C2932476
C15, C17: 100nF; C_0603_1608Metric_Pad1.08x0.95mm_HandSolder; MPN CL10B104KB8NNNC; LCSC C1591
D1: MRA4004T3G; D_SMA; MPN MRA4004T3G; LCSC C40324
D2: LESD5D5.0CT1G; D_SOD-523; MPN LESD5D5.0CT1G; LCSC C5199159
D3: green; LED_0603_1608Metric_Pad1.05x0.95mm_HandSolder; MPN YLED0603G; LCSC C19273151
D4: blue; LED_0603_1608Metric_Pad1.05x0.95mm_HandSolder; MPN YLED0603B; LCSC C19171394
D5: red; LED_0603_1608Metric_Pad1.05x0.95mm_HandSolder; MPN YLED0603R; LCSC C19171390
F1: RUILON SMD1812P050TF/30; D_1812_4532Metric_Pad1.30x3.40mm_HandSolder; MPN SMD1812P050TF/30; LCSC C12559
FID1, FID2, FID3: Fiducial; Fiducial_0.5mm_Mask1.5mm
H1, H2, H3: MountingHole_3.2mm_M3_DIN965_Pad; LCSC C3020132
H4, H5, H6, H7: e; MountingHole_3.2mm_M3
J1: Screw_Terminal_01x02; TerminalBlock_Phoenix_MKDS-1,5-2-5.08_1x02_P5.08mm_Horizont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; LCSC C8465
J2: Barrel_Jack_MountingPin; BarrelJack_Horizontal
J3: Analogique 0-3.3V; PinHeader_1x03_P2.54mm_Vertical
J4: Conn_01x04_Pin; JST_PH_S4B-PH-K_1x04_P2.00mm_Horizontal
J5: Screw_Terminal_01x02; TerminalBlock_4Ucon_1x02_P3.50mm_Horizontal; LCSC C784940
J6: GPS; PinSocket_1x05_P2.54mm_Vertical
J7: Conn_01x06_Pin; JST_XH_B6B-XH-A_1x06_P2.50mm_Vertical
J8, J9, J12, J13, J14, J15, J18, J19: Conn_01x03_Pin; PinHeader_1x03_P2.54mm_Vertical; MPN HB-PH3-25413PB2GOP; LCSC C6332196
J10, J11, J16, J17: Screw_Terminal_01x04; TerminalBlock_Phoenix_MKDS-3-4-5.08_1x04_P5.08mm_Horizontal; MPN WJ500V-5.08-4p; LCSC C42377749
JP1: SolderJumper_2_Open; SolderJumper-2_P1.3mm_Open_RoundedPad1.0x1.5mm
JP2, JP3, JP4, JP6: SolderJumper_3_Open; SolderJumper-3_P1.3mm_Open_Pad1.0x1.5mm
JP5, JP7: SolderJumper_2_Open; SolderJumper-2_P1.3mm_Open_TrianglePad1.0x1.5mm
R1, R2, R3, R13, R14, R24: 2.2k; R_0603_1608Metric_Pad0.98x0.95mm_HandSolder; MPN RC0603FR-072K2L; LCSC C114662
R4: 150R .1%; R_0805_2012Metric; MPN PTFR0805B150RN9; LCSC C351609
R5, R6, R15, R16: 10k; R_0603_1608Metric; MPN RC0603FR-0710kL; LCSC C98220
R7, R8, R17, R18: 1k; R_0603_1608Metric; MPN RC0603FR-071kL; LCSC C22548
R9, R10, R11, R12, R19, R20, R21, R22, R23: 2k5; R_0603_1608Metric; MPN AR03BTC2501; LCSC C304065
R25, R26, R27, R28: 150R-->100R .1%; R_0805_2012Metric; MPN PTFR0805B150RN9; LCSC C351609->C328435
TP1, TP2, TP3, TP4, TP5: TestPoint; Pin_D0.7mm_L6.5mm_W1.8mm_FlatFork
U1: TSR2-2450; Converter_DCDC_TRACO_TSR2-xxxx_THT; MPN TSR2-2450; LCSC C5198099
U3: BTS7004-1EPP; Infineon_PG-TSDSO-14-22; MPN BTS7004-1EPP; LCSC C534825
U4: ADS1115IDGS; TSSOP-10_3x3mm_P0.5mm; MPN ADS1115IDGSR; JLCPCB Part C37593
U5, U6, U7, U8: PC817; DIP-4_W8.89mm_SMDSocket_LongPads; MPN PC817CS; LCSC C20612591
U9: GY-NEO6MV2_25_36
U10: XIAO-ESP32-S3-DIP; XIAO-ESP32S3-DIP

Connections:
3V3_OUT: C14.1, C15.1, J4.3, J7.3, JP2.3 (B), JP4.1 (A), R1.1, R2.1, R5.2, R6.2, R13.1, R15.2, R16.2, TP3.1, U10.12 (VCC_3V3); also elsewhere on the board
5V: C4.1, C5.1, C6.1, C9.1, C10.1, D2.1 (K), J3.2, J7.5, J8.1, J9.1, J14.1, J15.1, JP2.1 (A), JP4.3 (B), TP5.1, U1.3 (OUT), U10.14 (VBUS); also elsewhere on the board
12V: C2.1, C3.1, C7.1, F1.2, JP1.2 (B), U1.1 (IN), U3.15 (VS)
12V_OUT: C8.1, C18.1, J5.1, J7.6, J8.3, J9.3, J14.3, J15.3, JP1.1 (A), R14.1, TP4.1, U3.8 (OUT), U3.9 (OUT), U3.10 (OUT), U3.12 (OUT), U3.13 (OUT), U3.14 (OUT)
ESP_LED: R24.1, U10.1 (GPIO1/D0/A0); also elsewhere on the board
GND: C1.2, C2.2, C3.2, C4.2, C5.2, C6.2, C7.2, C8.2, C9.2, C10.2, C11.2, C12.2, C13.2, C14.2, C15.2, C16.2, C17.2, C18.2, D2.2 (A), D3.1 (K), D4.1 (K), D5.1 (K), H1.MP, H2.MP, H3.MP, J1.2, J2.2, J2.MP (MountPin), J3.3, J4.4, J6.2, J7.4, J10.3, J11.3, J16.3, J17.3, JP7.2 (B), R4.2, R9.2, R11.2, R19.2, R21.2, R23.2, R25.2, R26.2, R27.2, R28.2, U1.2 (GND), U3.1 (GND), U4.3 (GND), U5.3, U6.3, U7.3, U8.3, U9.4 (Gnd), U10.13 (GND); also elsewhere on the board
unnamed: C1.1, D1.2 (A), J1.1, J2.1
unnamed: D1.1 (K), F1.1
unnamed: D3.2 (A), R13.2
unnamed: D4.2 (A), R14.2
unnamed: D5.2 (A), R24.2
unnamed: C11.1, J3.1, JP3.3 (B)
unnamed: J5.2, JP3.1 (A), R4.1
unnamed: C16.1, C17.1, J6.1, JP4.2 (C), U9.1 (Vcc)
unnamed: J8.2, J10.1, R10.1, U5.1
unnamed: J10.4, R7.2
unnamed: J9.2, J11.1, R12.1, U6.1
unnamed: J11.4, R8.2
unnamed: J12.1, R9.1
unnamed: J12.2, R7.1, U5.2
unnamed: J12.3, R10.2
unnamed: J13.1, R11.1
unnamed: J13.2, R8.1, U6.2
unnamed: J13.3, R12.2
unnamed: J14.2, J16.1, R20.1, U7.1
unnamed: J15.2, J17.1, R22.1, U8.1
unnamed: J16.4, R17.2
unnamed: J17.4, R18.2
unnamed: J18.1, R19.1
unnamed: J18.2, R17.1, U7.2
unnamed: J18.3, R20.2
unnamed: J19.1, R21.1
unnamed: J19.2, R18.1, U8.2
unnamed: J19.3, R22.2
unnamed: C12.1, C13.1, JP2.2 (C), JP5.2 (B), U4.8 (VDD)
unnamed: JP5.1 (A), JP7.1 (A), U4.1 (ADDR)
unnamed: JP6.2 (C), U4.7 (AIN3)
unnamed: R23.1, U3.3 (DEN)
unnamed: R3.2, U3.2 (IN)
SCL: J4.1, J7.1, R2.2, U4.10 (SCL), U10.6 (GPIO9/D5/I2C_SCL); also elsewhere on the board
SDA: J4.2, J7.2, R1.2, U4.9 (SDA), U10.5 (GPIO5/D4/I2C_SDA); also elsewhere on the board
debit1_4-20: J10.2, R25.1, U4.4 (AIN0)
debit2_4-20: J11.2, R26.1, U4.5 (AIN1)
debit3_4-20: J16.2, R28.1, U4.6 (AIN2)
debit4_4-20: J17.2, JP6.1 (A), R27.1
debit_centre_droit: R16.1, U8.4, U10.9 (GPIO7/D8/A8/SCK); also elsewhere on the board
debit_centre_gauche: R15.1, U7.4, U10.10 (GPIO8/D9/A9/MISO); also elsewhere on the board
debit_droit: R6.1, U6.4, U10.4 (GPIO4/D3/A3); also elsewhere on the board
debit_gauche: R5.1, TP2.1, U5.4, U10.3 (GPIO3/D2/A2); also elsewhere on the board
gps_rx: J6.4, U9.3 (Tx), U10.7 (U0TXD/D6/TX); also elsewhere on the board
gps_tx: J6.3, U9.2 (Rx), U10.8 (U0RXD/D7/RX); also elsewhere on the board
pression: JP3.2 (C), JP6.3 (B), TP1.1, U10.2 (GPIO2/DA/A1); also elsewhere on the board
pwr_12V_out: R3.1, U10.11 (GPIO9/D10/A10/MOSI); also elsewhere on the board

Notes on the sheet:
https://www.lcsc.com/datasheet/C20612594.pdf
Debitmetres
Black
ESP32
unused
White
DebitDouille V2.0 06/25
Power Pins 5V - This is 5v out from the USB port. You can also use this as a voltage input but you must have some sort of diode (schottky, signal, power) between your external power source and this pin with anode to battery, cathode to 5V pin. 3V3 - This is the regulated output from the onboard reg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
PNP
<< If = 50mA <<
GPS neo7M
0-3.3V
addr 0x4A
12V (max input 28V)
Power
pins debug, percages, etc
Connecteur Extension I2C
4 cD
/!\ plusieurs modèles choisis ne pas se fier au pinout, consulter la datasheet
power
ADC multiplexer
Microcontroleur
Avec 150 Ω : 4 mA → 0,004 A × 150 Ω = 0,6 V 20 mA → 0,02 A × 150 Ω = 3,0 V
bypass
En test V3.0
General
2 D
4-20
https://www.sikafrance.fr/fileadmin/products/france/datasheet/magnetic-inductive_flow_sensors/Datasheet_Magnetic_inductive_flow_sensors_VMZ.2_EN.pdf
--> analog ou 4-20 au choix
Brown
3 cG
Nicolas DAUY - FURGO
Objectif = - tester si la valeur est identique entre 4-20 et fréquence - tester si on a un gain de performance pour la lecture de pression - a terme créer la carte d'extension pour 4 debitmètre de plus
Cable orange : Marron = +Vcc Bleu = Gnd Blanc = 4-20 Noir = Freq
GPIO6
NPN
addr 0x49
1 G
Grove I2C

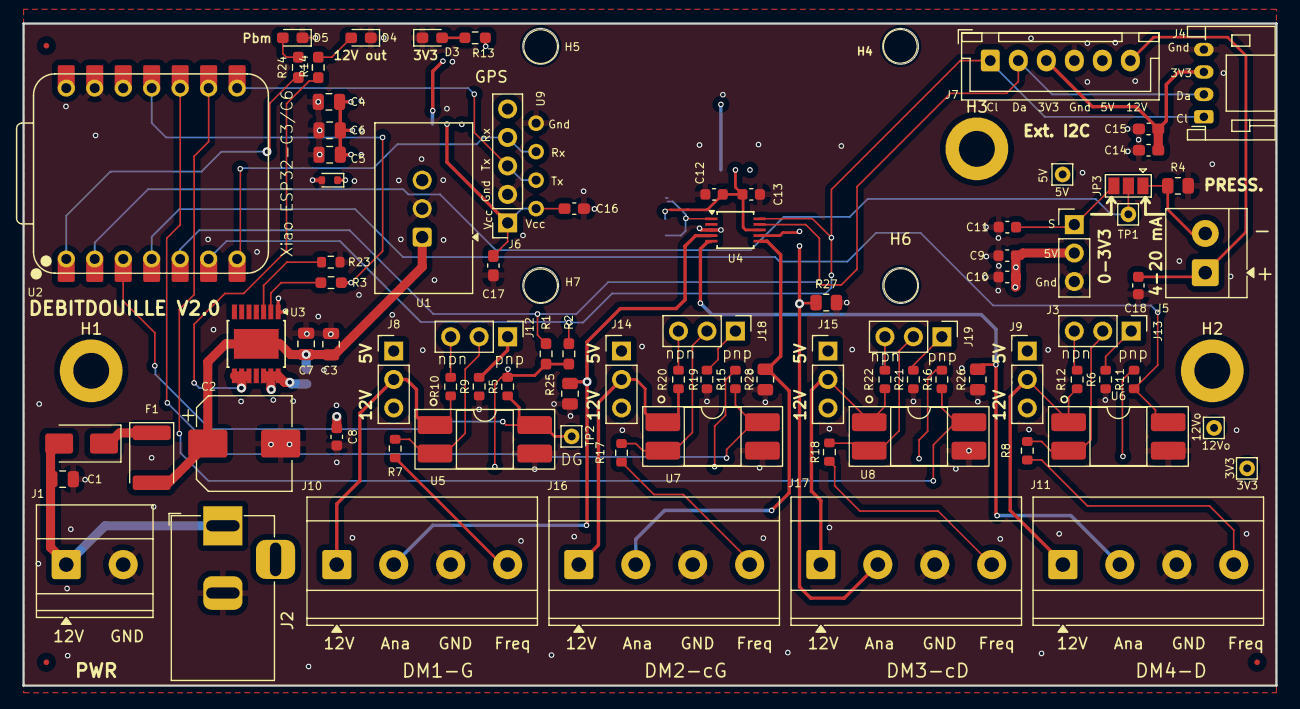
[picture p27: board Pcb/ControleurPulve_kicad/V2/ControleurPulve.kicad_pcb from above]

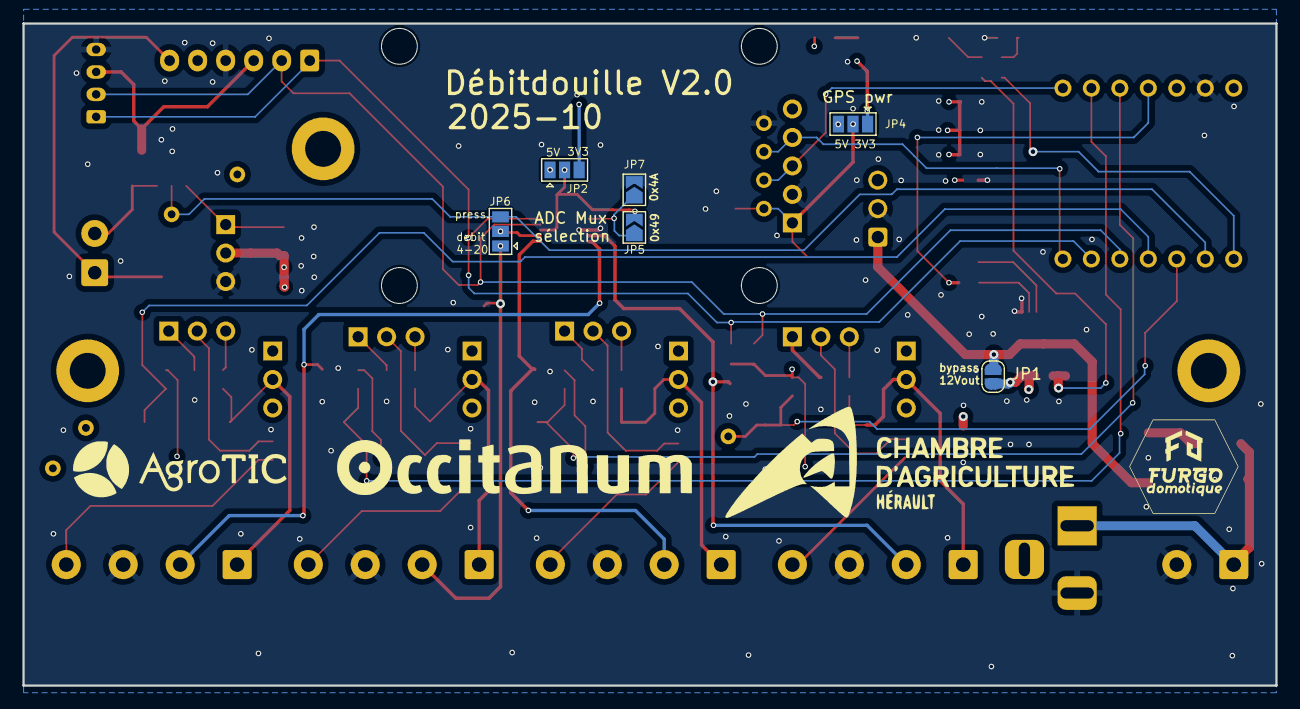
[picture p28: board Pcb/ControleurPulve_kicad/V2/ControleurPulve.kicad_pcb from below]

Board: 4 copper layers, 111.8 x 59.1 mm, 103 parts (6 on the bottom side), 53 nets.

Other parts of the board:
U2: XIAO-ESP32-C6; XIAO-ESP32C6-DIP

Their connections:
3V3_OUT: U2.12 (3V3); also elsewhere on the board
5V: U2.14 (VBUS); also elsewhere on the board
ESP_LED: U2.1 (GPIO0/A0/D0); also elsewhere on the board
GND: U2.13 (GND); also elsewhere on the board
SCL: U2.6 (GPIO23/D5/SCL); also elsewhere on the board
SDA: U2.5 (GPIO22/D4/SDA); also elsewhere on the board
debit_centre_droit: U2.9 (GPIO19/D8/SCK); also elsewhere on the board
debit_centre_gauche: U2.10 (GPIO20/D9/MISO); also elsewhere on the board
debit_droit: U2.4 (GPIO21/D3); also elsewhere on the board
debit_gauche: U2.3 (GPIO2/A2/D2); also elsewhere on the board
gps_rx: U2.7 (GPIO16/D6/TX); also elsewhere on the board
gps_tx: U2.8 (GPIO17/D7/RX); also elsewhere on the board
pression: U2.2 (GPIO1/A1/D1); also elsewhere on the board
pwr_12V_out: U2.11 (GPIO18/D10/MOSI); also elsewhere on the board

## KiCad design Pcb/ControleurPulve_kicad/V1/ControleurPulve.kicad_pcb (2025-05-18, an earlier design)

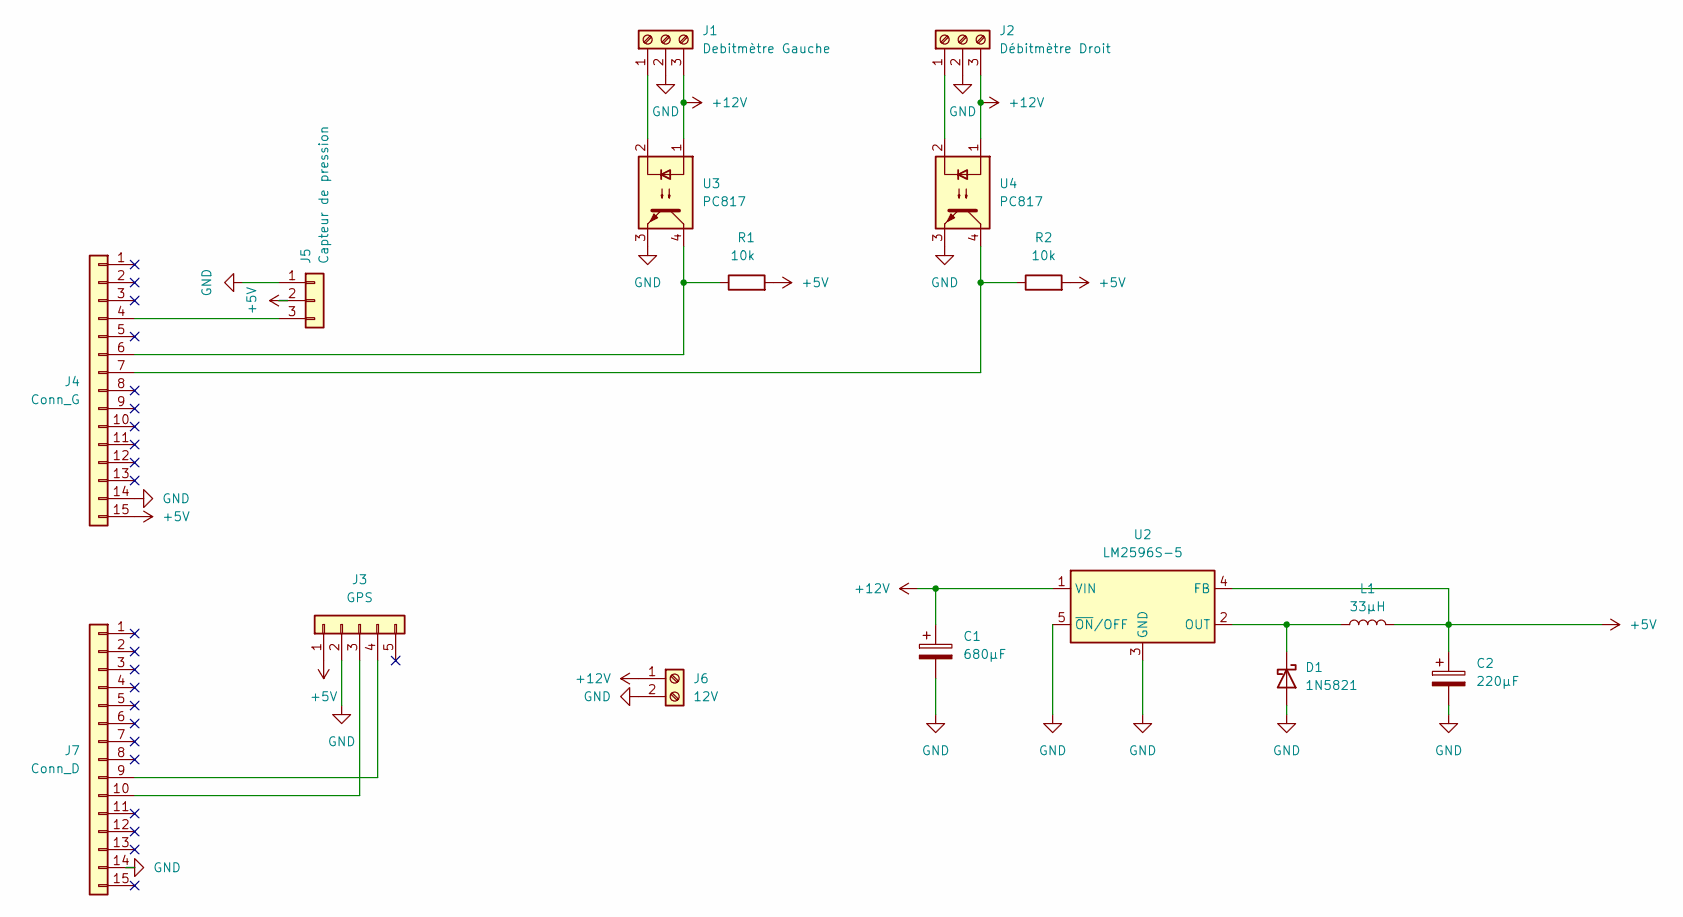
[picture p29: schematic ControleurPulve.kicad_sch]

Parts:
C1: 680µF; CP_Elec_10x10.5
C2: 220µF; CP_Elec_6.3x5.4
D1: 1N5821; D_DO-201AD_P12.70mm_Horizontal
J1: Debitmètre Gauche; TerminalBlock_bornier-3_P5.08mm
J2: Débitmètre Droit; TerminalBlock_bornier-3_P5.08mm
J3: GPS; PinSocket_1x05_P2.54mm_Vertical
J4: Conn_G; PinSocket_1x15_P2.54mm_Vertical
J5: Capteur de pression; PinHeader_1x03_P2.54mm_Vertical
J6: 12V; TerminalBlock_bornier-2_P5.08mm
J7: Conn_D; PinSocket_1x15_P2.54mm_Vertical
L1: 33µH; L_Changjiang_FXL0650
R1, R2: 10k; R_0603_1608Metric
U2: LM2596S-5; TO-263-5_TabPin3
U3, U4: PC817; OPTO-SMD4

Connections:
+5V: C2.1, J3.1, J4.15, J5.2, L1.2, R1.2, R2.2, U2.4 (FB)
+12V: C1.1, J1.3, J2.3, J6.1, U2.1 (VIN), U3.1, U4.1
GND: C1.2, C2.2, D1.2 (A), J1.2, J2.2, J3.2, J4.14, J5.1, J6.2, J7.14, U2.3 (GND), U2.5 (~ON/OFF), U3.3, U4.3
unnamed: D1.1 (K), L1.1, U2.2 (OUT)
unnamed: J1.1, U3.2
unnamed: J2.1, U4.2
unnamed: J3.3, J7.10
unnamed: J3.4, J7.9
unnamed: J4.4, J5.3
unnamed: J4.6, R1.1, U3.4
unnamed: J4.7, R2.1, U4.4

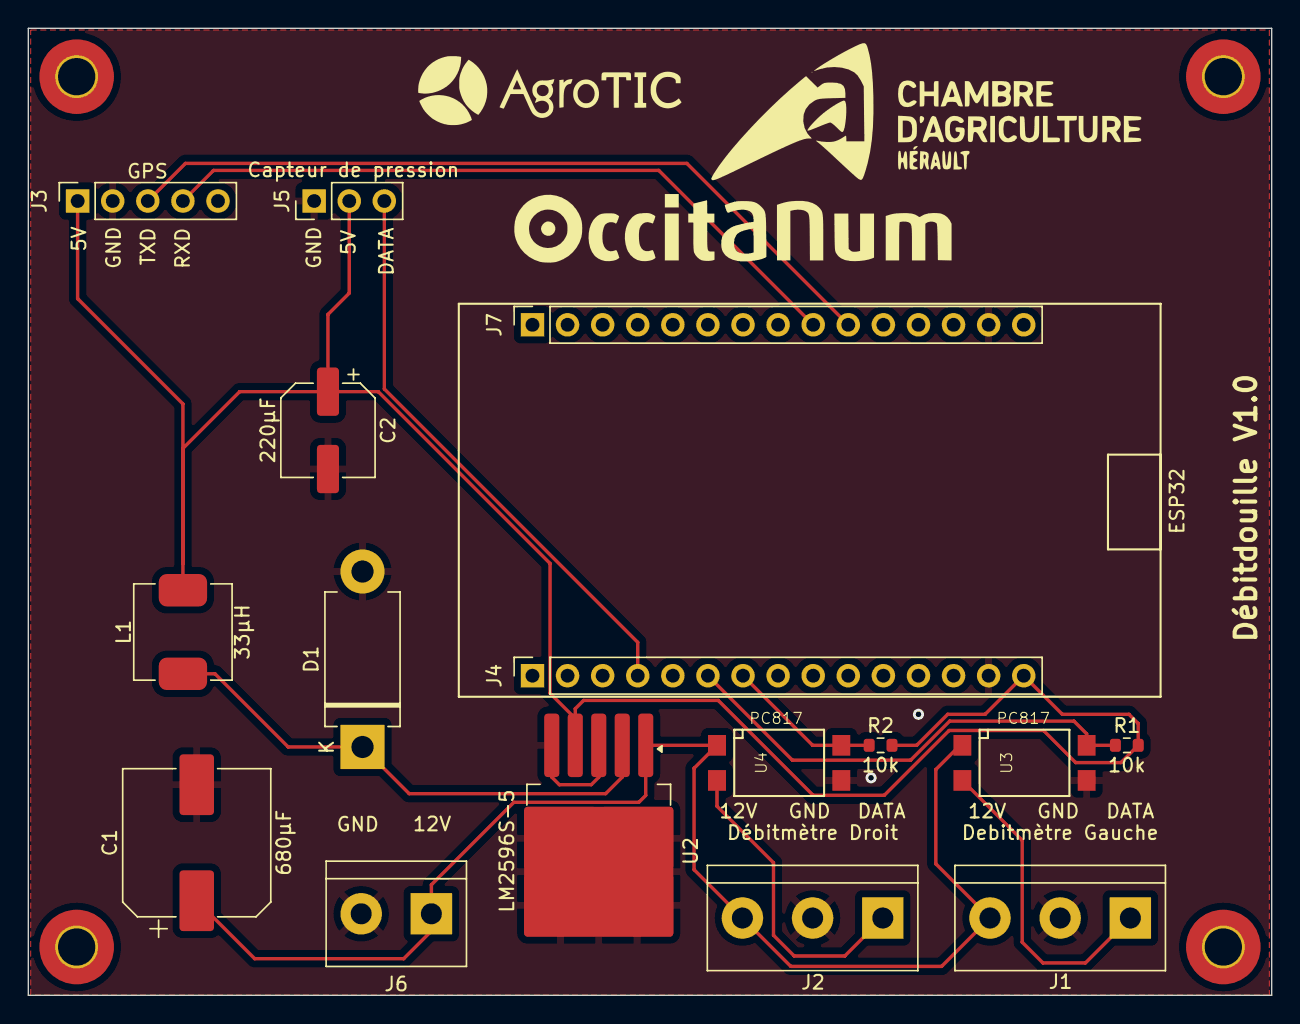
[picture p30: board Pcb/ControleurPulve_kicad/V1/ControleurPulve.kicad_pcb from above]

Board: 2 copper layers, 90.0 x 70.0 mm, 20 parts (0 on the bottom side), 11 nets.

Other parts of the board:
 : MountingHole_2.7mm_M2.5_Pad_TopBottom
 #2,  #3,  #4: MountingHole_2.7mm_M2.5_Pad_TopBottom

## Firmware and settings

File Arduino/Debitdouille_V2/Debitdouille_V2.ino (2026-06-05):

// Configuration de la version matérielle (à modifier selon votre carte)
#define V1          1  // Esp32 carte V1 (NodeMCU-32S)
#define V2_C3       2  // carte V2 XIAO ESP32-C3
#define V2_S3       3  // carte V2 XIAO ESP32-S3
#define DEBITDOUILLE_VERSION V1  // <-- Modifier ici pour changer de version

#include <BLEDevice.h>
#include <BLEServer.h>
#include <BLEUtils.h>
#include <BLE2902.h>
#include "Arduino.h"
#include <algorithm>
#include <Wire.h>
#include <TinyGPS++.h>
#include <Preferences.h>
#if DEBITDOUILLE_VERSION == V2_S3
    #include "driver/pcnt.h"  // PCNT uniquement pour ESP32-S3
#endif
#include <Adafruit_ADS1X15.h>
#include <ArduinoJson.h>

// ============================================
// 📌 INFORMATIONS FIRMWARE
// ============================================
#define FW_VERSION_MAJOR 2// version majeure, rétrocompatibilité souhaitée dans les avec l'app dans une même version majeure.
#define FW_VERSION_MINOR 1//TODO faire évoluer cela lors d'implémentation de fonctionnalités, en lien avec l'app flutter.
#define FW_BUILD_DATE __DATE__  // Date de compilation automatique
#define FW_BUILD_TIME __TIME__  // Heure de compilation automatique

// Modèle ESP selon la version hardware
#if DEBITDOUILLE_VERSION == V1
  #define FW_ESP_MODEL "ESP32-WROOM-32"
#elif DEBITDOUILLE_VERSION == V2_C3
  #define FW_ESP_MODEL "XIAO ESP32-C3"
#elif DEBITDOUILLE_VERSION == V2_S3
  #define FW_ESP_MODEL "XIAO ESP32-S3"
#else
  #define FW_ESP_MODEL "ESP32 Unknown"
#endif

HardwareSerial neogps(1);
Preferences preferences;
TinyGPSPlus gps;

// Configuration ADS1115
Adafruit_ADS1115 ads;  // Instance ADS1115 (adresse I2C par défaut 0x48)

// Constantes pour conversion 4-20mA DÉBITMÈTRES (via ADS1115)
#define SHUNT_RESISTOR 150.0      // Résistance de shunt en Ohms (150Ω actuel, 180Ω recommandé)
#define CURRENT_MIN 4.0           // Courant minimum 4mA
#define CURRENT_MAX 20.0          // Courant maximum 20mA
#define VOLTAGE_MIN (CURRENT_MIN * SHUNT_RESISTOR / 1000.0)   // 0.6V avec 150Ω
#define VOLTAGE_MAX (CURRENT_MAX * SHUNT_RESISTOR / 1000.0)   // 3.0V avec 150Ω
#define CURRENT_DISCONNECTED 3.5  // Seuil de détection déconnexion (<3.5mA)

// Constantes pour conversion 4-20mA PRESSION (en direct sur ESP32)
#define PRESSURE_SHUNT_RESISTOR 150.0    // Résistance de shunt pression en Ohms
#define PRESSURE_CURRENT_MIN 4.0          // Courant minimum 4mA
#define PRESSURE_CURRENT_MAX 20.0         // Courant maximum 20mA
#define PRESSURE_CURRENT_DISCONNECTED 3.5 // Seuil déconnexion pression (<3.5mA)

// ============= CALIBRATION DES DÉBITMÈTRES (VALEURS PAR DÉFAUT, PROGRAMMABLES PAR BLE) =============

// Débitmètres 4-20mA : Échelles maximales (L/min)
float maxFlow1 = 20.0;   // Canal 1: VMZ08 = 0-20 L/min
float maxFlow2 = 20.0;   // Canal 2: VMZ08 = 0-20 L/min
float maxFlow3 = 20.0;   // Canal 3: VMZ08 = 0-20 L/min
float maxFlow4 = 20.0;   // Canal 4: VMZ08 = 0-20 L/min

// Débitmètres PCNT/Interruptions : Nombre d'impulsions par litre
int NbImpulsionsDebitmetre1 = 1000;  // Canal 1: 1000 pulse/L par défaut
int NbImpulsionsDebitmetre2 = 1000;  // Canal 2: 1000 pulse/L par défaut
int NbImpulsionsDebitmetre3 = 1000;  // Canal 3: 1000 pulse/L par défaut
int NbImpulsionsDebitmetre4 = 1000;  // Canal 4: 1000 pulse/L par défaut

// ============= DÉLAIS DES TÂCHES FREERTOS (ms) =============
unsigned long delay_task1_ReadPulse =       1000;  //1000 Période d'échantillonnage PCNT (plus longue = plus précis). Ex : 65Hz => seulement 65 pulses en 1 seconde = 3.9L/min sur vmz08 => précision de 0.06L/min, si éch de 200ms => précision de 0.3L/min. 
unsigned long delay_task_ReadADS1115 =      200;   
unsigned long delay_task_ReadPressure =     500;   // Période de mise à jour de la pression
unsigned long delay_task_ReadGPS =          1000;   //1000
unsigned long delay_task_SendBLE =          1000;   //1000
unsigned long delay_task_HandleCommands =   50;   //
unsigned long delay_task_DebugSerial =      1000;   //

// UUIDs pour le service BLE - Nordic UART Service (NUS)
#define BLE_SERVICE_UUID "6E400001-B5A3-F393-E0A9-E50E24DCCA9E"     // Nordic UART Service
#define BLE_TX_CHAR_UUID "6E400003-B5A3-F393-E0A9-E50E24DCCA9E"     // TX Characteristic (ESP32 -> App)
#define BLE_RX_CHAR_UUID "6E400002-B5A3-F393-E0A9-E50E24DCCA9E"     // RX Characteristic (App -> ESP32)

BLEServer *pServer = NULL;
BLECharacteristic *pTxCharacteristic;
BLECharacteristic *pRxCharacteristic;
bool deviceConnected = false;
bool oldDeviceConnected = false;

// Configuration des broches
#if DEBITDOUILLE_VERSION == V1
#define PIN_PRESSURE 34
#define RXD2 16
#define TXD2 17
#define DEBITMETRE1_PIN 32
#define DEBITMETRE2_PIN 33
#define DEBITMETRE3_PIN 13//NOT USED
#define DEBITMETRE4_PIN 12//NOT USED
#define PIN_PWR_12V_OUT 14//NOT USED
#define PIN_LED         2
#define PIN_SDA         21  // I2C SDA par défaut ESP32
#define PIN_SCL         22  // I2C SCL par défaut ESP32
#elif  DEBITDOUILLE_VERSION == V2_C3//https://wiki.seeedstudio.com/XIAO_ESP32C3_Getting_Started/
#define PIN_PRESSURE 3
#define RXD2 20
#define TXD2 21
#define DEBITMETRE1_PIN 4 //Gauche
#define DEBITMETRE2_PIN 9//centre gauche 
#define DEBITMETRE3_PIN 8//centre droit 
#define DEBITMETRE4_PIN 5 //DROIT
#define PIN_SDA         6 //
#define PIN_SCL         7 //
#define PIN_LED         2 //
#define PIN_PWR_12V_OUT 10 //BTS7004
#elif  DEBITDOUILLE_VERSION == V2_S3//https://wiki.seeedstudio.com/xiao_esp32s3_getting_started/
#define PIN_PRESSURE 2
#define RXD2 44
#define TXD2 43
#define DEBITMETRE1_PIN 3 //Gauche
#define DEBITMETRE2_PIN 8 //centre gauche
#define DEBITMETRE3_PIN 7 //centre droit 
#define DEBITMETRE4_PIN 4 //DROIT
#define PIN_SDA         5 //
#define PIN_SCL         6 //
#define PIN_LED         1 //
#define PIN_PWR_12V_OUT 9 //BTS7004
#endif

// Variables pour l'auto-détection GPS RX/TX
uint8_t gpsRxPin = RXD2;           // Pin RX actuelle
uint8_t gpsTxPin = TXD2;           // Pin TX actuelle
uint16_t gpsFailCounter = 0;       // Compteur d'échecs de communication GPS
bool gpsPinsSwapped = false;       // Indicateur si les pins ont été inversés
#define GPS_FAIL_THRESHOLD 30      // Nombre d'échecs avant d'inverser les pins (30 secondes)
#define GPS_RETRY_THRESHOLD 60     // Nombre d'échecs avant de ré-inverser (si toujours pas de signal)
unsigned long lastGpsDataTime = 0; // Timestamp de la dernière donnée GPS valide

// Variables pour comptage des impulsions
#if DEBITDOUILLE_VERSION == V2_S3
    // PCNT pour ESP32-S3 (4 canaux)
    pcnt_unit_t pcntUnit1 = PCNT_UNIT_0;
    pcnt_unit_t pcntUnit2 = PCNT_UNIT_1;
    pcnt_unit_t pcntUnit3 = PCNT_UNIT_2;
    pcnt_unit_t pcntUnit4 = PCNT_UNIT_3;
    int16_t count1 = 0;
    int16_t count2 = 0;
    int16_t count3 = 0;
    int16_t count4 = 0;
#else
    // Comptage par interruptions pour ESP32-C3 et V1 (4 canaux)
    volatile uint32_t pulseCount1 = 0;
    volatile uint32_t pulseCount2 = 0;
    volatile uint32_t pulseCount3 = 0;
    volatile uint32_t pulseCount4 = 0;
    portMUX_TYPE mux1 = portMUX_INITIALIZER_UNLOCKED;
    portMUX_TYPE mux2 = portMUX_INITIALIZER_UNLOCKED;
    portMUX_TYPE mux3 = portMUX_INITIALIZER_UNLOCKED;
    portMUX_TYPE mux4 = portMUX_INITIALIZER_UNLOCKED;

    // Fonctions ISR pour interruptions
    void IRAM_ATTR pulseCounter1() {
        portENTER_CRITICAL_ISR(&mux1);
        pulseCount1++;
        portEXIT_CRITICAL_ISR(&mux1);
    }

    void IRAM_ATTR pulseCounter2() {
        portENTER_CRITICAL_ISR(&mux2);
        pulseCount2++;
        portEXIT_CRITICAL_ISR(&mux2);
    }

    void IRAM_ATTR pulseCounter3() {
        portENTER_CRITICAL_ISR(&mux3);
        pulseCount3++;
        portEXIT_CRITICAL_ISR(&mux3);
    }

    void IRAM_ATTR pulseCounter4() {
        portENTER_CRITICAL_ISR(&mux4);
        pulseCount4++;
        portEXIT_CRITICAL_ISR(&mux4);
    }
#endif

// Variables pour la réception Bluetooth
const byte numChars = 32;
char receivedChars[numChars];
char message[numChars] = {0};
char value[numChars] = {0};
boolean newData = false;

// Variables pour les constantes sauvegardées
int constDeb1, constDeb2, constDeb3, constDeb4;  // Débitmètres PCNT (pulse/L)
int constManA, constManB;  // Corrections manomètre
int constFlow1, constFlow2, constFlow3, constFlow4;  // Échelles débitmètres 4-20mA (L/min)

// Variables globales
String bluetoothMsg = "";
String messageRecu;
unsigned int valeurRecue;
String valeurRecueStr = "";  // Pour les commandes nécessitant une chaîne de caractères
int calib = 0;  // Calibration ADC en mV (0 = utilise uniquement la calibration interne ESP32)
int correctionManometreA = 100;  // Correction pente (100 = 1.00, pas de correction)
int correctionManometreB = 0;    // Correction offset en bars*100 (0 = pas de correction)
int pressureSensorType = 0;  // Type de capteur de pression: 0=Gravity analogique (0.5-4.5V, 0-16 bar), 1=4-20mA (0-16 bar)

// Nouveaux paramètres de calibration configurables (mode Tension 3 fils)
float pressureMaxBar = 16.0;      // Pression maximale du capteur (bar) - configurable via BLE
float pressureVoltageMin = 0.5;   // Tension minimale (V) - configurable via BLE
float pressureVoltageMax = 4.5;   // Tension maximale (V) - configurable via BLE

String deviceID = "";  // Identifiant unique du device (par défaut: 6 derniers caractères de l'adresse MAC)
float debit1, debit2, pressure, sat, lon, llat, sspeed;
unsigned long frameID = 0;  // ID incrémental de trame BLE pour détecter les pertes de paquets

// ============== FreeRTOS Configuration ==============
// Handles des tâches
TaskHandle_t taskPCNT = NULL;
TaskHandle_t taskADS1115 = NULL;
TaskHandle_t taskPressure = NULL;
TaskHandle_t taskGPS = NULL;
TaskHandle_t taskBLE = NULL;
TaskHandle_t taskCommands = NULL;
TaskHandle_t taskDebug = NULL;
TaskHandle_t taskLED = NULL;

// Mutex pour protéger les données partagées
SemaphoreHandle_t xMutexData = NULL;

// ============== LED Blink Control ==============
volatile int ledBlinkCount = 0;      // Nombre de clignotements à effectuer (0 = arrêté)
volatile int ledBlinkPeriod = 500;   // Période de clignotement en ms (par défaut 500ms)
SemaphoreHandle_t xMutexLED = NULL;  // Mutex pour protéger les paramètres LED

// Structure de données partagées entre les tâches
struct SensorData {
    float debit1;           // Débit PCNT/Interruption #1
    float debit2;           // Débit PCNT/Interruption #2
    float debit3;           // Débit PCNT/Interruption #3
    float debit4;           // Débit PCNT/Interruption #4
    float debit1_4_20mA;    // Débit 4-20mA canal 1
    float debit2_4_20mA;    // Débit 4-20mA canal 2
    float debit3_4_20mA;    // Débit 4-20mA canal 3
    float debit4_4_20mA;    // Débit 4-20mA canal 4
    bool sensor1_connected; // État connexion capteur 1
    bool sensor2_connected; // État connexion capteur 2
    bool sensor3_connected; // État connexion capteur 3
    bool sensor4_connected; // État connexion capteur 4
    float pressure;
    int pressureRawMilliVolts;  // Tension brute ADC en mV (debug/calibration)
    float sat;
    float lon;
    float llat;
    float sspeed;
} sensorData = {0};

// Configuration BLE
String device_name = "debitdouille-";

// Déclaration forward de la fonction LED
void triggerLEDBlink(int count, int period_ms);

// Callbacks BLE pour gérer la connexion
class MyServerCallbacks: public BLEServerCallbacks {
    void onConnect(BLEServer* pServer) {
      deviceConnected = true;
      Serial.println("Client connecté");
      // Déclencher 3 clignotements rapides lors de la connexion (200ms période)
      triggerLEDBlink(3, 200);
    };

    void onDisconnect(BLEServer* pServer) {
      deviceConnected = false;
      Serial.println("Client déconnecté");
      // Déclencher 1 clignotement long lors de la déconnexion (1000ms période)
      triggerLEDBlink(1, 1000);
    }
};

// Callback pour recevoir des données
class MyCallbacks: public BLECharacteristicCallbacks {
    void onWrite(BLECharacteristic *pCharacteristic) {
      std::string rxValue = pCharacteristic->getValue();

      if (rxValue.length() > 0) {
        String receivedString = "";
        for (int i = 0; i < rxValue.length(); i++) {
          receivedString += rxValue[i];
        }

        // Détection du format : JSON (commence par '{') ou ancien format "commande:valeur"
        if (receivedString.startsWith("{")) {
          // ========== FORMAT JSON ==========
          StaticJsonDocument<1024> doc;
          DeserializationError error = deserializeJson(doc, receivedString);

          if (error) {
            Serial.print("Erreur parsing JSON: ");
            Serial.println(error.c_str());
            return;
          }

          // Commande: get_coeff
          if (doc.containsKey("get_coeff") && doc["get_coeff"] == true) {
            messageRecu = "get_coeff";
            newData = true;
            Serial.println("Commande JSON reçue: get_coeff");
          }
          // Commande: get_info (infos firmware)
          else if (doc.containsKey("get_info") && doc["get_info"] == true) {
            messageRecu = "get_info";
            newData = true;
            Serial.println("Commande JSON reçue: get_info");
          }
          // Commande: update_coeff
          else if (doc.containsKey("update_coeff")) {
            messageRecu = "update_coeff";
            // Stocker le sous-objet pour traitement ultérieur dans taskHandleCommands
            valeurRecueStr = receivedString;  // Garder le JSON complet
            newData = true;
            Serial.println("Commande JSON reçue: update_coeff");
          }
          else {
            Serial.println("Commande JSON inconnue");
          }
        }
        else {
          // ========== FORMAT ANCIEN "commande:valeur" ==========
          int separatorIndex = receivedString.indexOf(':');
          if (separatorIndex > 0) {
            messageRecu = receivedString.substring(0, separatorIndex);
            String valeurStr = receivedString.substring(separatorIndex + 1);
            valeurRecue = valeurStr.toInt();
            valeurRecueStr = valeurStr;  // Garder aussi la version string
            newData = true;

            Serial.print("Message reçu (ancien format): ");
            Serial.print(messageRecu);
            Serial.print(" Valeur: ");
            Serial.println(valeurStr);
          }
        }
      }
    }
};

// Déclarations de fonctions
void setupPCNT();
// int calculerMedian();
// float calculerMoyenneSansOutliers();
void setupBLE();

void setupBLE() {
    // Initialiser le périphérique BLE
    BLEDevice::init(device_name.c_str());

    // Créer le serveur BLE
    pServer = BLEDevice::createServer();
    pServer->setCallbacks(new MyServerCallbacks());

    // Créer le service BLE (Nordic UART Service)
    BLEService *pService = pServer->createService(BLE_SERVICE_UUID);

    // Créer la caractéristique TX (ESP32 -> App)
    pTxCharacteristic = pService->createCharacteristic(
        BLE_TX_CHAR_UUID,
        BLECharacteristic::PROPERTY_NOTIFY
    );
    pTxCharacteristic->addDescriptor(new BLE2902());

    // Créer la caractéristique RX (App -> ESP32)
    pRxCharacteristic = pService->createCharacteristic(
        BLE_RX_CHAR_UUID,
        BLECharacteristic::PROPERTY_WRITE
    );
    pRxCharacteristic->setCallbacks(new MyCallbacks());

    // Démarrer le service
    pService->start();

    // Configurer et démarrer la publicité (advertising)
    BLEAdvertising *pAdvertising = BLEDevice::getAdvertising();
    pAdvertising->addServiceUUID(BLE_SERVICE_UUID);
    pAdvertising->setScanResponse(false);
    pAdvertising->setMinPreferred(0x0);
    BLEDevice::startAdvertising();

    Serial.println("En attente de connexion BLE...");
}

void setupPulseCounter() {
#if DEBITDOUILLE_VERSION == V2_S3
    // Configuration des pull-ups pour stabilité (comme les interruptions)
    pinMode(DEBITMETRE1_PIN, INPUT_PULLUP);
    pinMode(DEBITMETRE2_PIN, INPUT_PULLUP);
    pinMode(DEBITMETRE3_PIN, INPUT_PULLUP);
    pinMode(DEBITMETRE4_PIN, INPUT_PULLUP);

    // Configuration du PCNT pour ESP32-S3 (4 canaux)
    // Comptage sur front DESCENDANT (FALLING) comme les interruptions pour meilleure stabilité
    pcnt_config_t pcntConfig1 = {
        .pulse_gpio_num = DEBITMETRE1_PIN,
        .ctrl_gpio_num = PCNT_PIN_NOT_USED,
        .pos_mode = PCNT_COUNT_DIS,        // Pas de comptage sur front montant
        .neg_mode = PCNT_COUNT_INC,        // Comptage sur front descendant (FALLING)
        .counter_h_lim = 32767,
        .counter_l_lim = -32768,
        .unit = pcntUnit1,
        .channel = PCNT_CHANNEL_0,
    };
    pcnt_unit_config(&pcntConfig1);

    pcnt_config_t pcntConfig2 = {
        .pulse_gpio_num = DEBITMETRE2_PIN,
        .ctrl_gpio_num = PCNT_PIN_NOT_USED,
        .pos_mode = PCNT_COUNT_DIS,        // Pas de comptage sur front montant
        .neg_mode = PCNT_COUNT_INC,        // Comptage sur front descendant (FALLING)
        .counter_h_lim = 32767,
        .counter_l_lim = -32768,
        .unit = pcntUnit2,
        .channel = PCNT_CHANNEL_0,
    };
    pcnt_unit_config(&pcntConfig2);

    pcnt_config_t pcntConfig3 = {
        .pulse_gpio_num = DEBITMETRE3_PIN,
        .ctrl_gpio_num = PCNT_PIN_NOT_USED,
        .pos_mode = PCNT_COUNT_DIS,        // Pas de comptage sur front montant
        .neg_mode = PCNT_COUNT_INC,        // Comptage sur front descendant (FALLING)
        .counter_h_lim = 32767,
        .counter_l_lim = -32768,
        .unit = pcntUnit3,
        .channel = PCNT_CHANNEL_0,
    };
    pcnt_unit_config(&pcntConfig3);

    pcnt_config_t pcntConfig4 = {
        .pulse_gpio_num = DEBITMETRE4_PIN,
        .ctrl_gpio_num = PCNT_PIN_NOT_USED,
        .pos_mode = PCNT_COUNT_DIS,        // Pas de comptage sur front montant
        .neg_mode = PCNT_COUNT_INC,        // Comptage sur front descendant (FALLING)
        .counter_h_lim = 32767,
        .counter_l_lim = -32768,
        .unit = pcntUnit4,
        .channel = PCNT_CHANNEL_0,
    };
    pcnt_unit_config(&pcntConfig4);

    // Configuration du filtre glitch (anti-rebond)
    // Valeur = nombre de cycles APB (80MHz) pour filtrer les glitches
    // 1000 cycles @ 80MHz = 12.5 µs de filtrage
    // Rejette les pulses parasites < 12.5 µs (débitmètre pulse ~7-15 ms)
    pcnt_set_filter_value(pcntUnit1, 1000);
    pcnt_filter_enable(pcntUnit1);
    pcnt_set_filter_value(pcntUnit2, 1000);
    pcnt_filter_enable(pcntUnit2);
    pcnt_set_filter_value(pcntUnit3, 1000);
    pcnt_filter_enable(pcntUnit3);
    pcnt_set_filter_value(pcntUnit4, 1000);
    pcnt_filter_enable(pcntUnit4);

    pcnt_counter_pause(pcntUnit1);
    pcnt_counter_clear(pcntUnit1);
    pcnt_counter_resume(pcntUnit1);

    pcnt_counter_pause(pcntUnit2);
    pcnt_counter_clear(pcntUnit2);
    pcnt_counter_resume(pcntUnit2);

    pcnt_counter_pause(pcntUnit3);
    pcnt_counter_clear(pcntUnit3);
    pcnt_counter_resume(pcntUnit3);

    pcnt_counter_pause(pcntUnit4);
    pcnt_counter_clear(pcntUnit4);
    pcnt_counter_resume(pcntUnit4);

    Serial.println("PCNT initialisé avec filtre glitch (4 canaux - ESP32-S3)");
#else
    // Configuration des interruptions pour ESP32-C3 et V1 (4 canaux)
    pinMode(DEBITMETRE1_PIN, INPUT_PULLUP);
    pinMode(DEBITMETRE2_PIN, INPUT_PULLUP);
    pinMode(DEBITMETRE3_PIN, INPUT_PULLUP);
    pinMode(DEBITMETRE4_PIN, INPUT_PULLUP);

    attachInterrupt(digitalPinToInterrupt(DEBITMETRE1_PIN), pulseCounter1, FALLING);
    attachInterrupt(digitalPinToInterrupt(DEBITMETRE2_PIN), pulseCounter2, FALLING);
    attachInterrupt(digitalPinToInterrupt(DEBITMETRE3_PIN), pulseCounter3, FALLING);
    attachInterrupt(digitalPinToInterrupt(DEBITMETRE4_PIN), pulseCounter4, FALLING);

    Serial.println("Interruptions initialisées (4 canaux - ESP32-C3)");
#endif
}

// ============== Tâches FreeRTOS ==============

// Tâche 1: Lecture des débitmètres (toutes les 1000 ms)
void taskReadPulseCounters(void *pvParameters) {
    TickType_t xLastWakeTime = xTaskGetTickCount();
    const TickType_t xFrequency = pdMS_TO_TICKS(delay_task1_ReadPulse);  // 1000 ms

    unsigned long lastTime = millis();

    for(;;) {
        // Attendre le prochain cycle (précis à ±1ms)
        vTaskDelayUntil(&xLastWakeTime, xFrequency);

        unsigned long currentTime = millis();
        unsigned long deltaTime = currentTime - lastTime;//non utilisé si PCNT 

        uint32_t count1_local = 0;
        uint32_t count2_local = 0;
        uint32_t count3_local = 0;
        uint32_t count4_local = 0;
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
void loop() {
    // ============== Loop simplifié : gestion de la reconnexion BLE uniquement ==============
    // Toutes les autres tâches sont gérées par FreeRTOS (PCNT, Pression, GPS, BLE, Commandes)

    // Gestion de la reconnexion BLE
    if (!deviceConnected && oldDeviceConnected) {
        delay(500); // Délai avant de relancer la publicité
        pServer->startAdvertising();
        Serial.println("Relancement de la advertising BLE");
        oldDeviceConnected = deviceConnected;
    }
    // Connexion établie
    if (deviceConnected && !oldDeviceConnected) {
        Serial.println("Nouveau client BLE connecté");
        oldDeviceConnected = deviceConnected;
    }

    // Petit délai pour ne pas saturer le CPU
    delay(100);
}
  
// // Fonction pour calculer la médiane
// int calculerMedian() {
//     int valeursTriees[n];
//     memcpy(valeursTriees, mesures, sizeof(mesures));
//     std::sort(valeursTriees, valeursTriees + n);
//     return valeursTriees[n / 2];
// }

// // Fonction pour calculer la moyenne sans les outliers
// float calculerMoyenneSansOutliers() {
//     int mediane = calculerMedian();
//     int somme = 0;
//     int nombreDeValeurs = 0;
//     for (int i = 0; i < n; i++) {
//         if (abs(mesures[i] - mediane) <= 2) {
//             somme += mesures[i];
//             nombreDeValeurs++;
//         }
//     }
//     return somme / (float)nombreDeValeurs;
// }

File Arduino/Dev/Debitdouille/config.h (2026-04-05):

#pragma once

////////////////////////////////////
////////		PARAMETRAGE
////////////////////////////////////

#define VERSION "1.1"
#define BAUDRATE_DEBUG		115200UL//Baudrate Serial
#define BAUDRATE_GPS		9600UL//Baudrate Serial
#define debug_serial		true
#define debug_debitmetre	true
#define debug_pressure		true
#define debug_calc_pressure	true
#define debug_gps			true


#define ON				1
#define OFF				0



////////////////////////////////////
////////		PINS
////////////////////////////////////
#define PIN_DEBITMETRE1 34
#define PIN_DEBITMETRE2 33
#define PIN_DEBITMETRE3 32
#define PIN_DEBITMETRE4 31


// pin connexions
#define PIN_PRESSURE 34

//GPS pins
#define RXD2 16
#define TXD2 17


////////////////////////////////////
////////		Fonctions
////////////////////////////////////
//slog make the Serial.print run only if the QUIET argument of the command vector is not set
//Log make the Serial.print run only if the QUIET argument of the command vector is not set
#define slog(x) ((!debug_serial) ? 0 : Serial.print(x));
#define slogln(x) ((!debug_serial) ? 0 : Serial.println(x));
#define slogf(x, ...) ((!debug_serial) ? 0 : Serial.printf(x,__VA_ARGS__));

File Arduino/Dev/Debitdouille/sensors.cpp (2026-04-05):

// 
// 
// 

#include "sensors.h"
#include "config.h"
#include "driver/pcnt.h"  //
#include "esp_timer.h"  
#include <Ticker.h>  // Pour les timers asynchrones





///////////////////////////////////////
//          FLOW SENSOR
///////////////////////////////////////

Ticker mesure_debit_timer;  // Créer un timer pour mesurer le débit chaque seconde
volatile bool FLAG_DEBITMETRE;

// Instances des 4 débitmètres
const char* debit_name[] = { "Droit", "Gauche", "CentreDroit", "CentreGauche" };

float debitmetres_valeurs[4];
int NbImpulsionsDebitmetre1 = 1000;  //Pulses debitmetre gauche
int NbImpulsionsDebitmetre2 = 1000;  //Pulses debitmetre droit
int NbImpulsionsDebitmetre3 = 1000;  //Pulses debitmetre centre droit
int NbImpulsionsDebitmetre4 = 1000;  //Pulses debitmetre centre gauche
int NbImpulsionsDebitmetreArray[] = { NbImpulsionsDebitmetre1, NbImpulsionsDebitmetre2, NbImpulsionsDebitmetre3, NbImpulsionsDebitmetre4 }; // Pulses pour chaque débitmètre

//facteur de conversion impulsion débit 
#define PCNT_H_LIM_VAL 20000 // Limite haute du compteur pour tous les débitmètres

// Initialisation des 4 débitmètres
Debitmetre_t debitmetre[] = {
  {0, 0, 0, PCNT_UNIT_0, PCNT_CHANNEL_0, PIN_DEBITMETRE1, portMUX_INITIALIZER_UNLOCKED, NULL},
  {0, 0, 0, PCNT_UNIT_1, PCNT_CHANNEL_0, PIN_DEBITMETRE2, portMUX_INITIALIZER_UNLOCKED, NULL},
  {0, 0, 0, PCNT_UNIT_2, PCNT_CHANNEL_0, PIN_DEBITMETRE3, portMUX_INITIALIZER_UNLOCKED, NULL},
  {0, 0, 0, PCNT_UNIT_3, PCNT_CHANNEL_0, PIN_DEBITMETRE4, portMUX_INITIALIZER_UNLOCKED, NULL},
};

// Fonction de gestion d'interruption pour chaque débitmètre
void IRAM_ATTR pcnt_event_handler(void* arg)
{
    Debitmetre_t* debitmetre = (Debitmetre_t*)arg;
    uint32_t intr_status = 0;
    // Récupère le statut d'interruption pour l'unité
    pcnt_get_event_status(debitmetre->unit, &intr_status);

    // Si l'interruption est causée par une limite haute atteinte
    if (intr_status & PCNT_EVT_H_LIM) {
        portENTER_CRITICAL_ISR(&debitmetre->timer_mux);
        debitmetre->overflow_cnt++;
        portEXIT_CRITICAL_ISR(&debitmetre->timer_mux);
    }
    // Nettoie l'interruption pour l'unité
    pcnt_counter_clear(debitmetre->unit);
}

// Initialisation d'un débitmètre
void pcnt_init_debitmetre(Debitmetre_t* debitmetre)
{
    pinMode(debitmetre->gpio_pin, INPUT);
    pcnt_config_t pcnt_config = {
        .pulse_gpio_num = debitmetre->gpio_pin,
        .ctrl_gpio_num = -1,
        .lctrl_mode = PCNT_MODE_KEEP,
        .hctrl_mode = PCNT_MODE_KEEP,
        .pos_mode = PCNT_COUNT_INC,
        .neg_mode = PCNT_COUNT_INC,
        .counter_h_lim = PCNT_H_LIM_VAL,
        .counter_l_lim = 0,
        .unit = debitmetre->unit,
        .channel = debitmetre->channel
    };

    pcnt_unit_config(&pcnt_config);
    pcnt_isr_register(pcnt_event_handler, debitmetre, 0, NULL);
    pcnt_set_filter_value(debitmetre->unit, 2000);  // Filtrage des glitches
    pcnt_filter_enable(debitmetre->unit);
    pcnt_counter_pause(debitmetre->unit);
    pcnt_counter_clear(debitmetre->unit);
    pcnt_event_enable(debitmetre->unit, PCNT_EVT_H_LIM);  // Déclenchement si dépassement de la limite
    pcnt_counter_resume(debitmetre->unit);

    esp_timer_create_args_t timer_args = {
        .callback = pcnt_get_counter,
        .arg = debitmetre,
        .name = "flowmeter timer"
    };

    if (esp_timer_create(&timer_args, &debitmetre->timer_handle) != ESP_OK)
    {
        Serial.printf("Erreur lors de la création du timer pour le débitmètre GPIO : %d\n", debitmetre->gpio_pin);
    }
}

// Fonction pour convertir les impulsions en débit en L/min
double convert_impulsion_debit(uint8_t id_debitmetre, uint16_t impulsions) {
    // Conversion des impulsions en fréquence (Hz)
    // https://fr.aliexpress.com/item/33011866648.html
    // Ici, on suppose que le temps écoulé est de 1 seconde entre chaque lecture
    double frequence = impulsions;  // Si la période de mesure est 1 seconde
    // Conversion de la fréquence en débit en L/min selon la formule du capteur
    double debit = frequence / NbImpulsionsDebitmetreArray[id_debitmetre];  // Q = F / 21
    return debit;
}

// Récupération de la valeur du compteur pour un débitmètre
void pcnt_get_counter(void* p)
{
    Debitmetre_t* debitmetre = (Debitmetre_t*)p;
    pcnt_counter_pause(debitmetre->unit);  // Pause du compteur
    pcnt_get_counter_value(debitmetre->unit, (int16_t*)&debitmetre->result);  // Récupère la valeur
    debitmetre->flow = convert_impulsion_debit(debitmetre->unit, debitmetre->result);  // Conversion des impulsions en débit (L/min)
    pcnt_counter_clear(debitmetre->unit);  // Remise à zéro du compteur après récupération
    pcnt_counter_resume(debitmetre->unit); // Reprise du comptage
}



// Fonction qui sera appelée chaque seconde pour mesurer les débits
void mesure_debit() {
    for (int i = 0; i < 4; i++) {
        Debitmetre_t* d = &debitmetre[i];
        pcnt_get_counter(d); // Lire la valeur pour chaque débitmètre
        debitmetres_valeurs[i] = d->flow;
    }
    FLAG_DEBITMETRE = true;
}

// Initialisation de tous les débitmètres
void pcnt_init_all_debitmetres()
{
    for (int i = 0; i < 4; i++) {  // Nous n'avons que 4 unités PCNT disponibles
        pcnt_init_debitmetre(&debitmetre[i]);
    }
}



///////////////////////////////////////
//          PRESSURE
///////////////////////////////////////
volatile bool FLAG_PRESSION;
Ticker mesure_pression_timer;  // Créer un timer pour mesurer le débit chaque seconde
float pressure;
const int n = 20; // Nombre de valeurs à prendre en compte
int mesures[n];
int calib = 415;

void mesure_pression() {

    FLAG_PRESSION = true;
}
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

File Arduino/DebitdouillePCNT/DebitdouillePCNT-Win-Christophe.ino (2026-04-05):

#include "BluetoothSerial.h"
#include "Arduino.h"
#include <algorithm>
#include <Wire.h>
#include <TinyGPS++.h>
#include <Preferences.h>
#include "driver/pcnt.h"

HardwareSerial neogps(1);
Preferences preferences;
TinyGPSPlus gps;

// Configuration des broches
#define PIN_PRESSURE 34
#define RXD2 16
#define TXD2 17
#define DEBITMETRE1_PIN 32
#define DEBITMETRE2_PIN 33

// Constantes
const unsigned long period = 1000;
const unsigned long periodPressure = 20;
const int n = 20; // Nombre de valeurs pour le filtre médian
unsigned int constDeb1;
unsigned int constDeb2;
unsigned int constManA;
unsigned int constManB;

// Variables PCNT
pcnt_unit_t pcntUnit1 = PCNT_UNIT_0;
pcnt_unit_t pcntUnit2 = PCNT_UNIT_1;
int16_t count1 = 0;
int16_t count2 = 0;

// Variables globales
String bluetoothMsg = "";  //Message sent through Bluetooth
String messageRecu;
unsigned int valeurRecue;
int calib = 415;
int NbImpulsionsDebitmetre1 = 4000;
int NbImpulsionsDebitmetre2 = 4000;
int correctionManometreA = 70;
int correctionManometreB = 70;
int mesures[n];
int ind = 0;
float debit1, debit2, pressure, sat, lon, llat, sspeed;
bool newData = false;
unsigned long startMillis;
unsigned long currentMillis;
unsigned long startMillisPressure;
unsigned long currentMillisPressure;

// variables for sensor
int val, prescbar;

char receivedChars[32];  // Variable to store the received data
char message[16];        // Variable to store the part before the ':'
char value[16];          // Variable to store the part after the ':'

// Configuration Bluetooth
//#define USE_PIN // Uncomment this to use PIN during pairing. The pin is specified on the line below
const char *pin = "1234";
String device_name = "S21";
BluetoothSerial SerialBT;

void setupPCNT() {
    // Configuration du PCNT pour le débitmètre 1
    pcnt_config_t pcntConfig1 = {
        .pulse_gpio_num = DEBITMETRE1_PIN,
        .ctrl_gpio_num = PCNT_PIN_NOT_USED,
        .pos_mode = PCNT_COUNT_INC,
        .neg_mode = PCNT_COUNT_DIS,
        .counter_h_lim = 32767,
        .counter_l_lim = -32768,
        .unit = pcntUnit1,
        .channel = PCNT_CHANNEL_0,
    };
    pcnt_unit_config(&pcntConfig1);
    
    // Configuration du PCNT pour le débitmètre 2
    pcnt_config_t pcntConfig2 = {
        .pulse_gpio_num = DEBITMETRE2_PIN,
        .ctrl_gpio_num = PCNT_PIN_NOT_USED,
        .pos_mode = PCNT_COUNT_INC,
        .neg_mode = PCNT_COUNT_DIS,
        .counter_h_lim = 32767,
        .counter_l_lim = -32768,
        .unit = pcntUnit2,
        .channel = PCNT_CHANNEL_0,
    };
    pcnt_unit_config(&pcntConfig2);
    
    // Démarrer les compteurs
    pcnt_counter_pause(pcntUnit1);
    pcnt_counter_clear(pcntUnit1);
    pcnt_counter_resume(pcntUnit1);
    
    pcnt_counter_pause(pcntUnit2);
    pcnt_counter_clear(pcntUnit2);
    pcnt_counter_resume(pcntUnit2);
}
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

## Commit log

2025-03-26 Rename Liste Matériel Débitdouille.xlsx to Liste Matériel Débitdouille.xlsx
    [Liste Matériel Débitdouille.xlsx]
2025-05-12 Ajout electronique initiale
    [ControleurPulve.kicad_pcb, ControleurPulve.kicad_sch, untitled.kicad_sch]
2025-08-21 Ajout de l'appli V1.0 en flutter
2025-09-01 Avancement schematic
    [ControleurPulve.kicad_sch]
2025-10-17 Electronique V2 schematic (non routée)
    [ControleurPulve.kicad_pcb, ControleurPulve.kicad_sch, ControleurPulve.step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]
2025-10-19 PCB : silkscreen et placement (non routé)
    [ControleurPulve.kicad_pcb, ControleurPulve.kicad_sch]
2025-10-21 Mise en prod
    [BOMControleurPulve2.xlsx, ControleurPulve.kicad_pcb, ControleurPulve.kicad_sch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]
2025-11-04 Dév PCB : en cours de validation PCB reçus Code V2
    [BOM_complementaire.xlsx, ControleurPulve.kicad_pcb, ControleurPulve.kicad_sch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]
2025-11-05 App flutter : - reconnexion automatique - scan BLE automatique - verification perte de trame - calibration debitmètres Arduino : - formatage des données envoyées - trame de calibration
2025-11-05 App flutter : calibration pression (2 modèles), calibration debit choix de la source.
2025-11-05 Code arduino V2.1 Code flutter V2.1 Ajout versionning.
2025-11-07 Patch arduino : - mix de namespace dans les préférences NVS (application mauvais modèle capteur pression par défaut) - erreur d'allocation débitmètre droit
2025-11-07 Reset des valeurs à 0 quand il détecte reconnexion en cours
2026-04-05 3D printing supports
    [supportCarte.FCStd, supportCarte.stl]
2026-06-05 feat: précision d'affichage réglable, lissage, gestion erreurs BLE
    Versions
    - App Flutter : 2.0.2+2 (patch)
    - Firmware : patch mapping débitmètre V1 (cible active V2_S3)
    App Flutter
    - Précision d'affichage réglable par grandeur (pression / débits / vitesse), 0 à 3 décimales, défaut 1 décimale
    - Moyenne glissante (fenêtre 5 trames) pour stabiliser l'affichage des valeurs
    - Scan BLE : message clair + bouton lorsque le Bluetooth est désactivé (activation via popup système) ou la localisation coupée
    - Barre debug JSON : police réduite, zone scrollable, plus de troncature ni de chevauchement avec la navigation
    - Correctif : parsing de la source du débitmètre DD3 (lisait la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
    [Debitdouille_V2.ino]
